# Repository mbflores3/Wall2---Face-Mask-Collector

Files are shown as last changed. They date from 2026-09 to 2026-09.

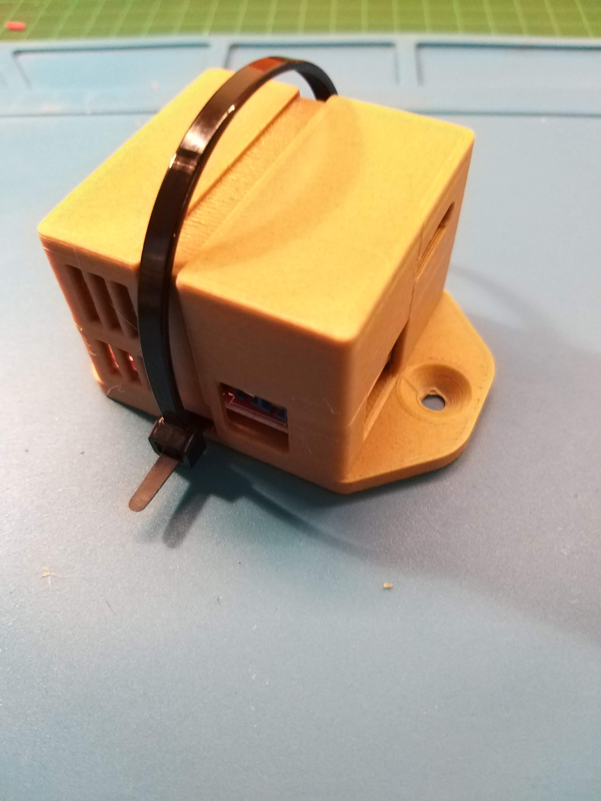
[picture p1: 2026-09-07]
Casing/3328541_L298N_Case_with_Zip-Tie_closure_and_Screw_holes_for_placement/images/20190102_104234.jpg

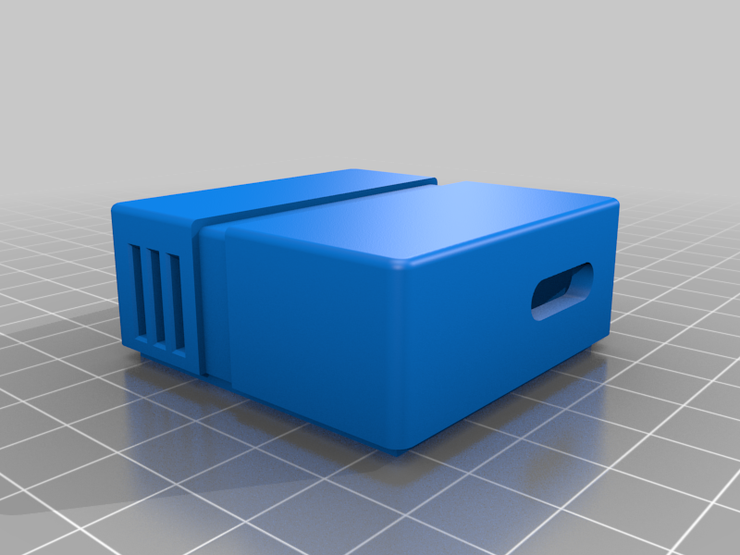
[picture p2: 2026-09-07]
Casing/3328541_L298N_Case_with_Zip-Tie_closure_and_Screw_holes_for_placement/images/L298N_Case_1.0.3c.png

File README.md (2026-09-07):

# Wall2---Face-Mask-Collector
## 1. User Manual

### 1.1. Required Hardware and Software

To begin this user manual, the components needed to build the prototype are listed below:

#### Mechanical Components:

• 2 MDF boards, 6mm thick, 600 x 440 mm (one for each floor).

• 2 rigid couplings, 5mm to 8mm.

• 2 rigid couplings, 8mm to 8mm.

• 4 rigid couplings, 6mm to 8mm.

• 4 Monster Truck toy wheels for sand.

• 4 dowels with nuts.

• 4 axles, 8mm in diameter and 8cm long.

• 2 kg of PLA 3D printing material.

• 1 trash can, 190mm wide.

• Screws and nuts of various diameters.

• 4 L-type couplings for Pololu DC motors.

• 4 Bearing Mounts

#### Electrical Components:

• ESP32 dev kit

• Arduino MEGA

• Raspberry Pi 4b

• 6 PC817 Optocouplers

• 6 Pre-drilled Breadboards (11cm x 6cm, 6cm x 4cm, 7cm x 3cm x4)
• 12 10kΩ Resistors

• Male Pin Header

• Female Pin Header

• 2 XH-M400 8A Step-Down Voltage Regulators

• 2 L298N H-Bridges

• 4 Pololu 12V DC Motors with Encoders

• 4 MG995 Servo Motors

• 1 ADXL345 Accelerometer-Gyroscope
• 2 11.1V 2200mAh LiPo Batteries

• 1 x 14.8V 5200mAh LiPo battery

• 3 x 2-pin 21x15mm switches

• 2 x XT60 female connectors

• 1 x XT60U-F female connector

• 1 x 640x480 pixel webcam

• 1 x HC-SR04 sonar sensor

• Logic jumper wires and power cables

• 2 x Arduino-type USB cables

• 1 x USB Type-C cable

• Cable ties

#### Software, knowledge, and computing tools requirements

• Arduino IDE

• 1 computer with a Python programming environment (preferably VS Code)

• Operating system installation software (preferably Rufus)

• Raspberry Pi operating system

• Minimum Python libraries: NumPy, Serial, OpenCV, Imutils, Time, SciPy
• Minimum Arduino Libraries: Simple_MPU6050, Servo.

#### Other necessary tools

• 3D printer.

• CNC laser cutter.

• Allen wrench set.

• Screwdriver set.

• Pliers.

• Hot glue gun.

### 1.2. Installation, assembly, and configuration

#### Assembly:

• Cut the MDF wood panels with the laser cutter. The first panel is cut according to the design in the Piso1_v1.dxf file, and the second according to the Piso2_v2.dxf file. These pieces correspond to floors one and two of the prototype.

• 3D print the component housings using the following files: motor_housing.ipt for the motors, L298N_Case_1.0.3b.stl and L298N_Case_1.0.3c.stl for the H-bridges, arduino_mega_case.ipt for the Arduino Mega, and battery_housing.ipt and lipo_housing.ipt for the batteries.

• On the board corresponding to the first level, assemble the DC motors with their respective L-shaped brackets. Then, place a 6-8mm coupling between the motor shaft and an 8mm shaft, one bearing per motor, and place them inside their respective housings and screw them in.

• Place the H-bridges inside their respective housings and screw them between the motors (one for every two motors).

• Using a hot glue gun, glue three optocouplers next to each H-bridge. The optocouplers should be arranged in parallel from the H-bridges towards the center of the chassis. • Using the pre-drilled boards, design the PCBs described in Appendix 7.3 and carefully attach them to the chassis as needed.

• Place the Arduino Mega in its housing and assemble it to the chassis in the most suitable location (preferably near the optocouplers).

• Connect the couplings to the wheels and assemble them to the shaft of each motor.

• Place the batteries in their housings and assemble them on the back of the motor.

• Assemble the arm with the respective servos and position them inside according to the arm's schematics presented in the low-level diagram.

• Place the servos on the arm's base in their respective housings and then attach the base to the arm.

• Assemble the arm to the chassis.

#### Connections:

• Connect an on/off switch to each battery.

• Connect four wires (two power and two ground) to the output of a battery. Connect these wires to the two H-bridges (one power and one ground for each H-bridge).
• Connect six wires from the H-bridges, corresponding to logic pins, to the optocouplers.
• Connect six wires from the optocouplers to a PCB (available in Appendix 7.3). This PCB receives the signals from the optocouplers and connects to the Arduino Mega at the corresponding pins (available in the low-level diagram).
• Connect the motor encoders to the PCB in a way that allows easy connection to the ESP32.
• The ESP32 receives the encoders, a power wire, and a ground wire.
• Once the connections are made and the second level is assembled, connect the Raspberry Pi to the Arduino Mega via serial communication. This will allow you to send information to the Arduino to control the motors.

• Connect the webcam to the Raspberry Pi via serial communication.

#### Software Installation:

• Go to the official Raspberry Pi website to download the operating system.

• Download the OS called "Raspberry Pi OS (64-bit)".

• Download Rufus from its official website.

• Open Rufus, select the downloaded operating system, and connect the SD card where you will create the partition. Start the installation process.

• Once the process is complete, remove the SD card and insert it into the Raspberry Pi.

• Connect the Raspberry Pi to a monitor via HDMI, and connect a mouse and keyboard. Then, power on the Raspberry Pi.

• Follow the installation instructions.

• Open Rufus, select the downloaded operating system, and connect the mouse and keyboard. • After installing the OS, open a terminal and run the following commands:

$ pip 3 install numpy
$ pip 3 install script
$ pip 3 install multils
$ pip 3 install opencv-python

• Transfer the .py files from the code folder.

• Upload the Wall2_MARK5.ino file to the Arduino Mega and the Wall2_ESP32.ino file to the ESP32 using the Arduino IDE.

• Connect the Arduino Mega and the ESP32 to the Raspberry Pi using a USB connection.

### 1.3. Instructions for use
• Turn on the power switch for the Raspberry Pi and the other controllers.

• Turn on the power switches for the motors and servos.

• Run the code “Wall2_MARK5.py”

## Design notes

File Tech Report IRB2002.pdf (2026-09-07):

IRB2002 – Diseño de Sistemas Robóticos

Escuela de Ingeniería / Major en Sistemas Autónomos y Robóticos

Pontificia Universidad Católica de Chile

# Informe Final

## Diseño de Sistemas Robóticos

## Grupo N◦ 3

## Mario Flores Martín Gallegos Agustín Mondinelli Jorge Pérez

12.12.2022

IRB2002 – Diseño de Sistemas Robóticos

Pontificia Universidad Católica de Chile

## Tabla de Contenidos

3.1. | Comparación de primera carta Gantt con el desarrollo del proyecto . . . . | 24
© Escuela de Ingeniería / Major en Sistemas Autónomos y Robóticos. | 2

Pontificia Universidad Católica de Chile | Informe Final

## 1. Estado final del proyecto

### 1.1. Descripción del proyecto

En los últimos años, dada la contingencia sanitaria, se ha evidenciado el incremento de residuos quirúrgicos desechados en lugares públicos como calles, parques y playas, y en particular, la contingencia ha llevado al aumento en casi un 9000% los residuos de mascarillas solo entre marzo y octubre del 2020 [1], lo que implica en un riesgo para la salud de las personas que concurren a estos lugares. Por lo tanto, la solución que se propone es un robot capaz de recorrer las playas para recoger y almacenar mascarillas que se encuentran tiradas por donde éste circule. El robot tendrá la capacidad de reconocer lo que es una mascarilla para poder recogerla. Además, otra característica que tendrá es que su movimiento no requerirá de la presencia humana para funcionar y operar. Y, por último, el robot tendrá un sistema de almacenamiento que le permita llevar todas las mascarillas que encuentra, y así poder trasladarse de manera más óptima.

### 1.2. Requerimientos

Los requerimientos que nos hemos propuesto para que el proyecto cumpla con los objetivos son los siguientes.

- Tiempo de recolección máximo dos veces inferior a un humano promedio.
- Tiempo de autonomía de por lo menos una hora.
- Área de trabajo: 128 m²
(área de cancha de voleibol).
- Capacidad de resistencia y adaptación a terrenos adversos (viento, arena y humedad).
- Sistema de detección y recolección de mascarillas.
- Capacidad de reconocer el entorno para recorrer un área delimitada.

Respecto al primer requerimiento, no se logró cumplirlo. Esto se debe principalmente a la manera en que se desarrollaron los movimientos del robot desde que detecta una mascarilla hasta que la recoge, siendo esto un proceso lento. Si se hubiera implementado un control PID más fino y que el movimiento del brazo robótico actuara al mismo tiempo en que el robot se desplaza, entonces se hubiera recolectado mascarillas en un menor tiempo que el obtenido.

Ahora bien, sobre el segundo objetivo, no se ha logrado comprobar que el robot tenga una autonomía de al menos una hora, ya que no se han hecho pruebas durante tanto tiempo sin detenerse. Pero considerando que una batería estaba solamente destinada a alimentar los motores DC y otra batería destinada a alimentar los Servo Motores, entonces estimamos que el robot sí puede cumplir con este requerimiento.

© Escuela de Ingeniería / Major en Sistemas Autónomos y Robóticos. | 3

Sobre el área de trabajo que se estableció en 128 m²
, consideramos que el robot es capaz de cumplir con el tercer requerimiento. Ahora bien, se mencionó anteriormente que nunca se han hecho pruebas para verificar si el robot efectivamente tiene una autonomía de al menos una hora, por lo que tampoco se sabe si es capaz de recorrer toda el área sin problemas. Pero sabiendo la capacidad de las baterías, entonces permite pensar que sí cumple con el objetivo.

Respecto al cuarto requerimiento, se ha comprobado que un poco de viento no afecta al funcionamiento ni a los componentes del robot. Por otro lado, el robot nunca fue expuesto a humedad, por lo que no podemos concluir nada respecto a esto. Pero sobre la arena, hemos construido un robot que no es completamente sellado, y por lo tanto durante las pruebas efectuadas, al robot le entró mucha arena donde se encuentran los componentes, aunque ninguno de ellos falló durante las pruebas. Para lograr este requerimiento se debe sellar al robot por completo y que ninguno de los componentes quede expuesto a estar en contacto con la arena.

Por otro lado, sobre el quinto requerimiento, se ha cumplido de buena manera con la implementación del sistema de detección y recolección de mascarillas. Gracias al código desarrollado para segmentar y detectar una mascarilla, y también al código que permite ejecutar los movimientos del brazo robótico, como resultado se obtuvo una segmentación bastante precisa y una fluidez en el movimiento del brazo.

Finalmente, sobre el sexto requerimiento, finalmente se descartó la idea de que el robot sea capaz de reconocer el entorno y sus límites. Lo que se hizo fue implementar un protocolo que recorre un camino definido según la distancia que se traslada. Pero el problema con esto es que finalmente se quemó la ESP32, la cual estaba encargada de leer los encoders de los motores DC, por lo que en el protocolo se cambió distancia recorrida por tiempo de ejecución, lo que no es muy factible en la práctica.

### 1.3. Especificaciones

Las especificaciones requeridas se pueden clasificar según el área de aplicación.

- Mecánicas

– Ruedas con diseño para tracción en arena.

– Material de chasis resistente a la arena y humedad.

– Sistema de pick-up con dos grados de libertad

– Recipiente disponible para almacenamiento de mascarillas con orificios para filtrado de arena.

– Mecanismo accionador capaz de sostener objetos de por lo menos 50g (Peso mascarillas + arena residual).

- Eléctricas
© Escuela de Ingeniería / Major en Sistemas Autónomos y Robóticos. | 4

– Regulador de voltaje para componentes electrónicos (Sensores y Actuadores).

– Motores DC con capacidad de torque suficiente para el objetivo propuesto (Dependiendo si son para tracción o para sistema de pick-up, desde 0.504 hasta 2.24 Nm).

– Sensor de distancia para retroalimentar el sistema de pick-up (Sonar).

– Fuente de alimentación: 2 baterías de 11.1 V y 2200 mah, considerando 4 motores de tracción de 150 ma, 2 servomotores de 300 ma, y la alimentación de microcontroladores que es de 1300 ma en sus puntos críticos.

– Sensores de orientación y aceleración para retroalimentar el estado del robot (Giroscopio y acelerómetro).

- Computacionales

– Algoritmo de segmentación de mascarillas mediante procesamiento de imágenes.

– Protocolo de exploración del área de trabajo.

– Proceso de filtrado para estimación del estado del robot.

– Microcontrolador con capacidad de procesamiento y memoria suficiente para cumplir con los algoritmos escogidos.

– Capturadora de imágenes de resolución de al menos 416 x 416 y un frame rate de por lo menos 2fps.

### 1.4. Normas y Estándares

A continuación se mencionan los estándares que fueron elegidos para construir el robot.

- ISO 18646-1:2016 [2]: Define métodos y criterios para evaluar el rendimiento de un robot de servicio. Este estándar se enfoca específicamente en el desplazamiento de robots con ruedas. Resulta útil para evaluar el movimiento del robot en desarrollo.
- ISO 18646-3:2021 [3]: Define métodos de evaluación de rendimiento de robots de servicio en la manipulación de objetos. Se evalúan aspectos como: tamaño del manipulador, fuerza de agarre, resistencia al deslizamiento, entre otros. Resulta útil para desarrollar un sistema de pick-up adecuado.
- Certificación IP [4]: Según la numeración de la certificación, se establece el grado de resistencia que tiene un sistema eléctrico a la exposición de polvo y agua. En el caso de este proyecto, la certificación necesaria corresponde a IP66.
- ISO 19649:2017 [5]: Entrega definiciones y vocabulario frecuentemente utilizados en robótica.

Nuestro robot en uno tal que utiliza 4 ruedas para desplazarse. Por lo que, sobre el estándar ISO 18646-1:2016, nuestro robot cumple con las especificaciones, puesto que es capaz de moverse de buena manera y rápida sin presentar problemas.

© Escuela de Ingeniería / Major en Sistemas Autónomos y Robóticos. | 5

Por otro lado, consideraos que el robot cumple con el estándar ISO 18646-3:2021, ya que hemos sido capaces de implementar un brazo tal que tiene un tamaño bastante reducido y liviano, la fuerza que realiza es suficiente y la mascarilla no se resbala o cae cuando el gripper logra agarrarla. Considerando todo esto, entonces el sistema de pick-up implementado es adecuado para lo que se necesita.

Ahora bien, sobre la certificación IP66, no se puede concluir nada sobre si el sistema eléctrico resiste a la exposición de agua, ya que no se realizaron pruebas con agua o en un ambiente húmedo. Pero sobre la resistencia al polvo, o en este caso a la arena, si bien el sistema eléctrico estuvo muy expuesto a la arena, pero ninguno de los componentes falló debido a esta situación, por lo que no fue posible verificar si el robot es capaz de cumplir con dicha certificación.

### 1.5. Diagrama de Alto Nivel

El diagrama de alto nivel final se encuentra en la figura 1, la cual se divide en 6 bloques principales: Fuente de alimentación, acondicionamiento, controlador, sensores, actuadores y aislamiento.

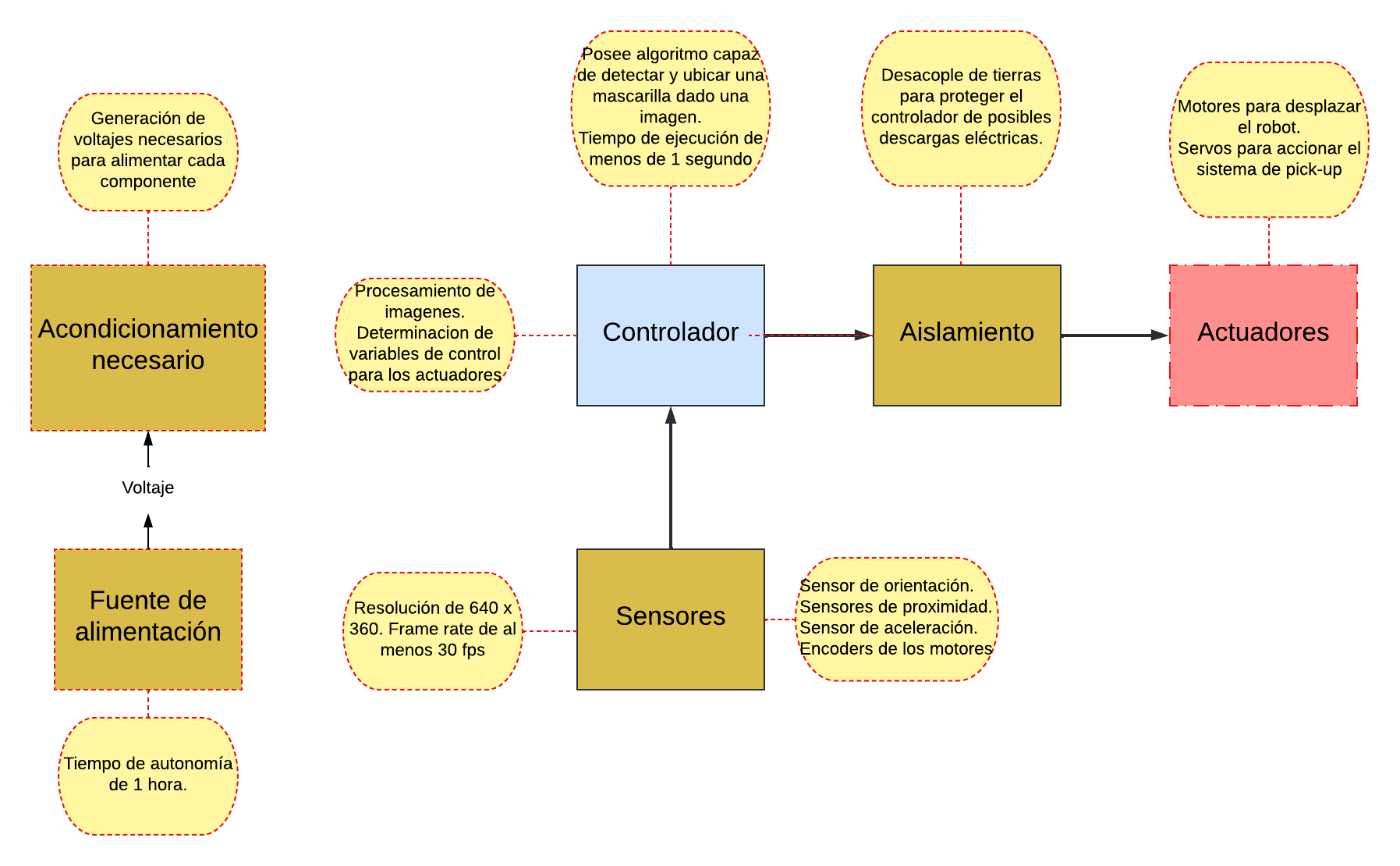
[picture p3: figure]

Figura 1: Diagrama de alto nivel

© Escuela de Ingeniería / Major en Sistemas Autónomos y Robóticos. | 6

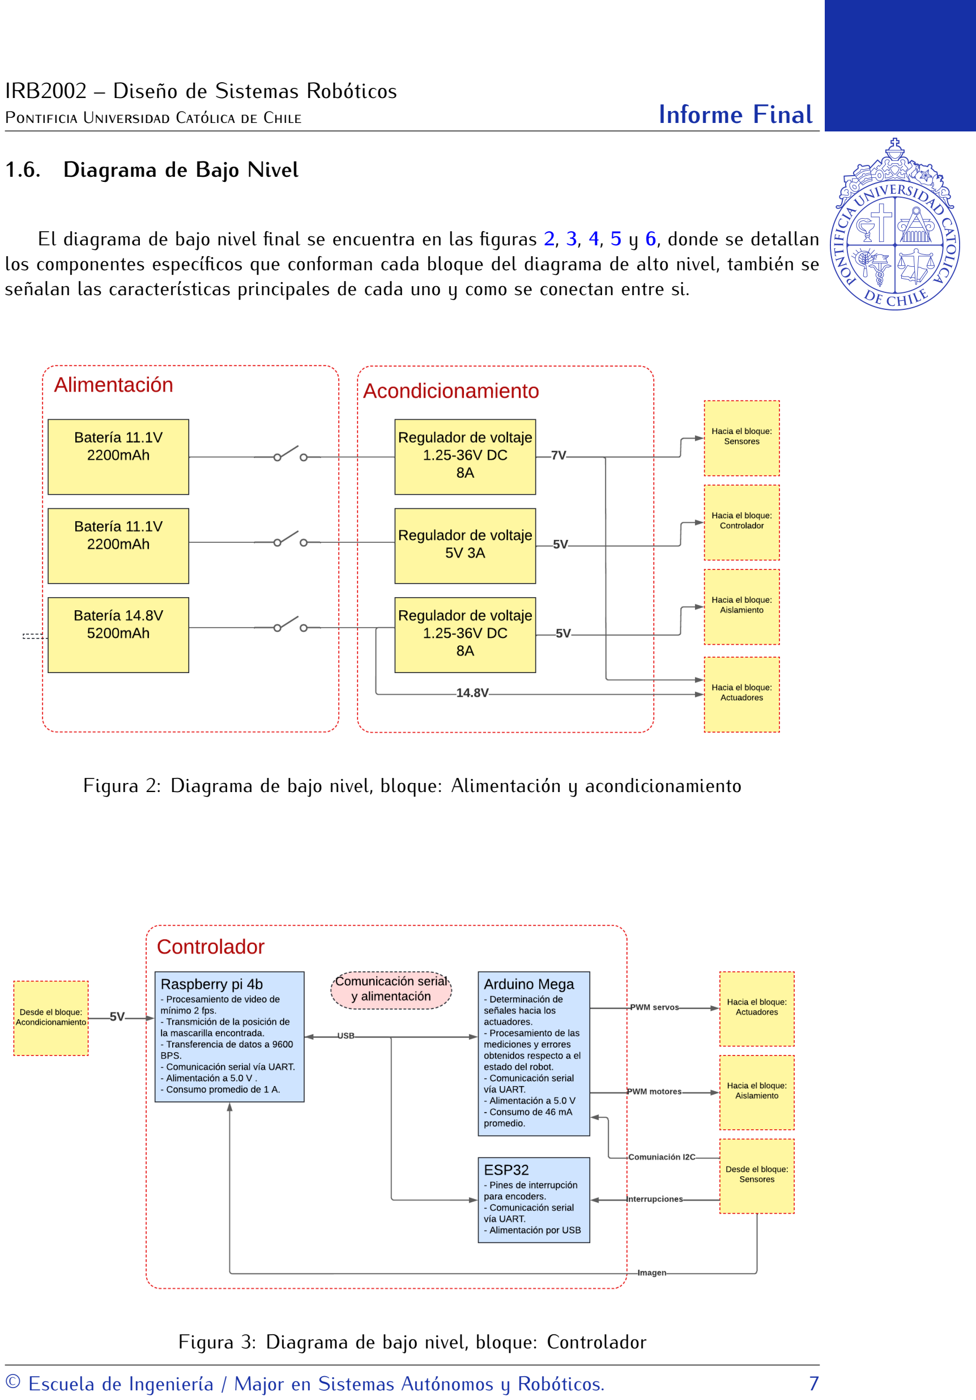
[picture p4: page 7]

### 1.6. Diagrama de Bajo Nivel

El diagrama de bajo nivel final se encuentra en las figuras 2, 3, 4, 5 y 6, donde se detallan los componentes específicos que conforman cada bloque del diagrama de alto nivel, también se señalan las características principales de cada uno y como se conectan entre si.

Figura 2: Diagrama de bajo nivel, bloque: Alimentación y acondicionamiento

Figura 3: Diagrama de bajo nivel, bloque: Controlador

© Escuela de Ingeniería / Major en Sistemas Autónomos y Robóticos. | 7

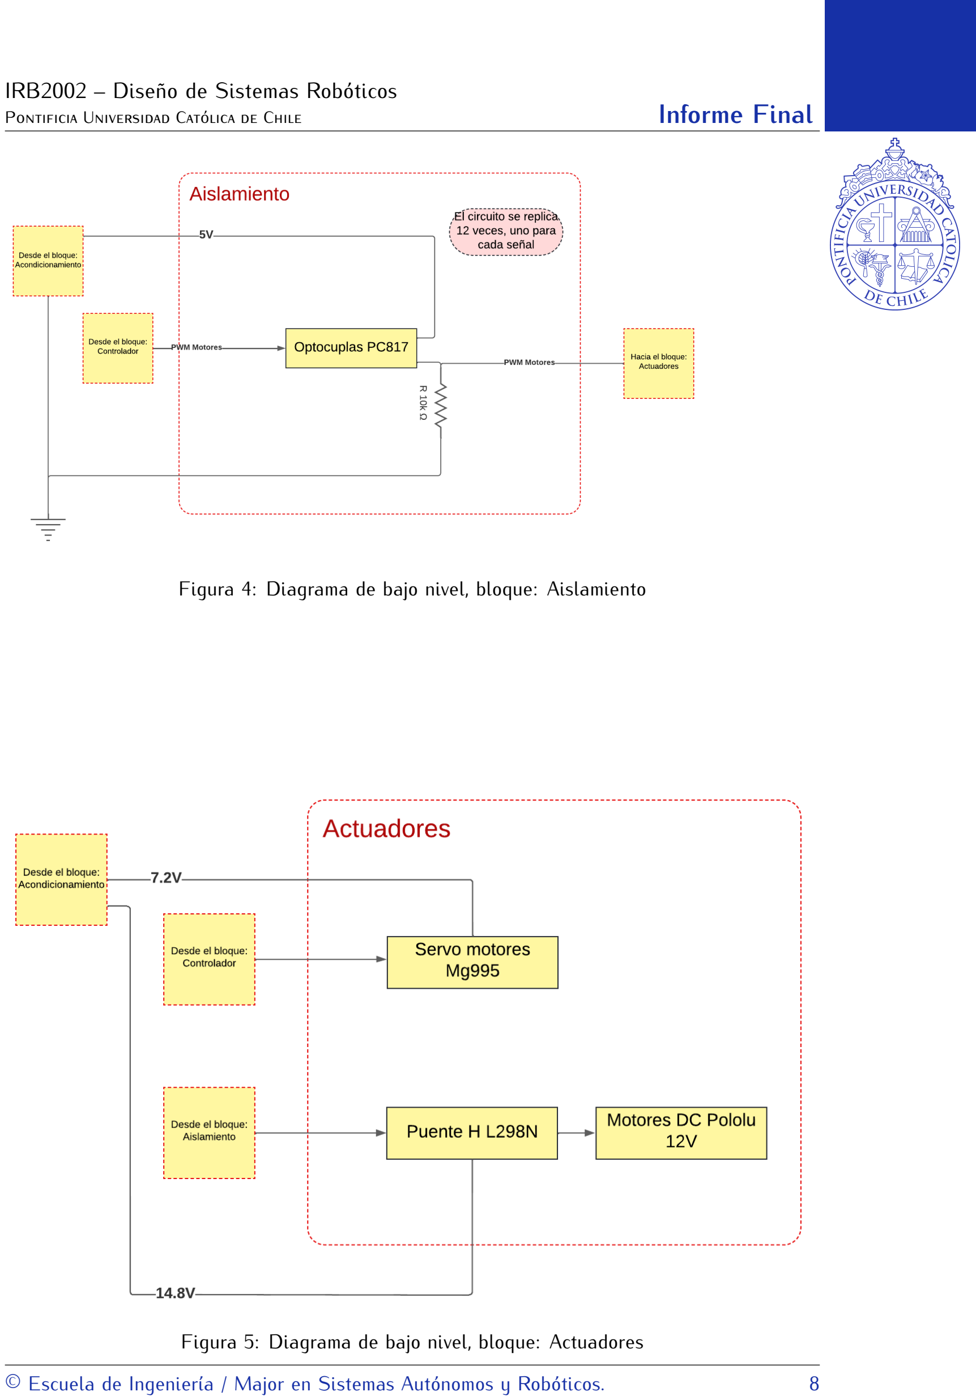
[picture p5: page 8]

Figura 4: Diagrama de bajo nivel, bloque: Aislamiento

Figura 5: Diagrama de bajo nivel, bloque: Actuadores

© Escuela de Ingeniería / Major en Sistemas Autónomos y Robóticos. | 8

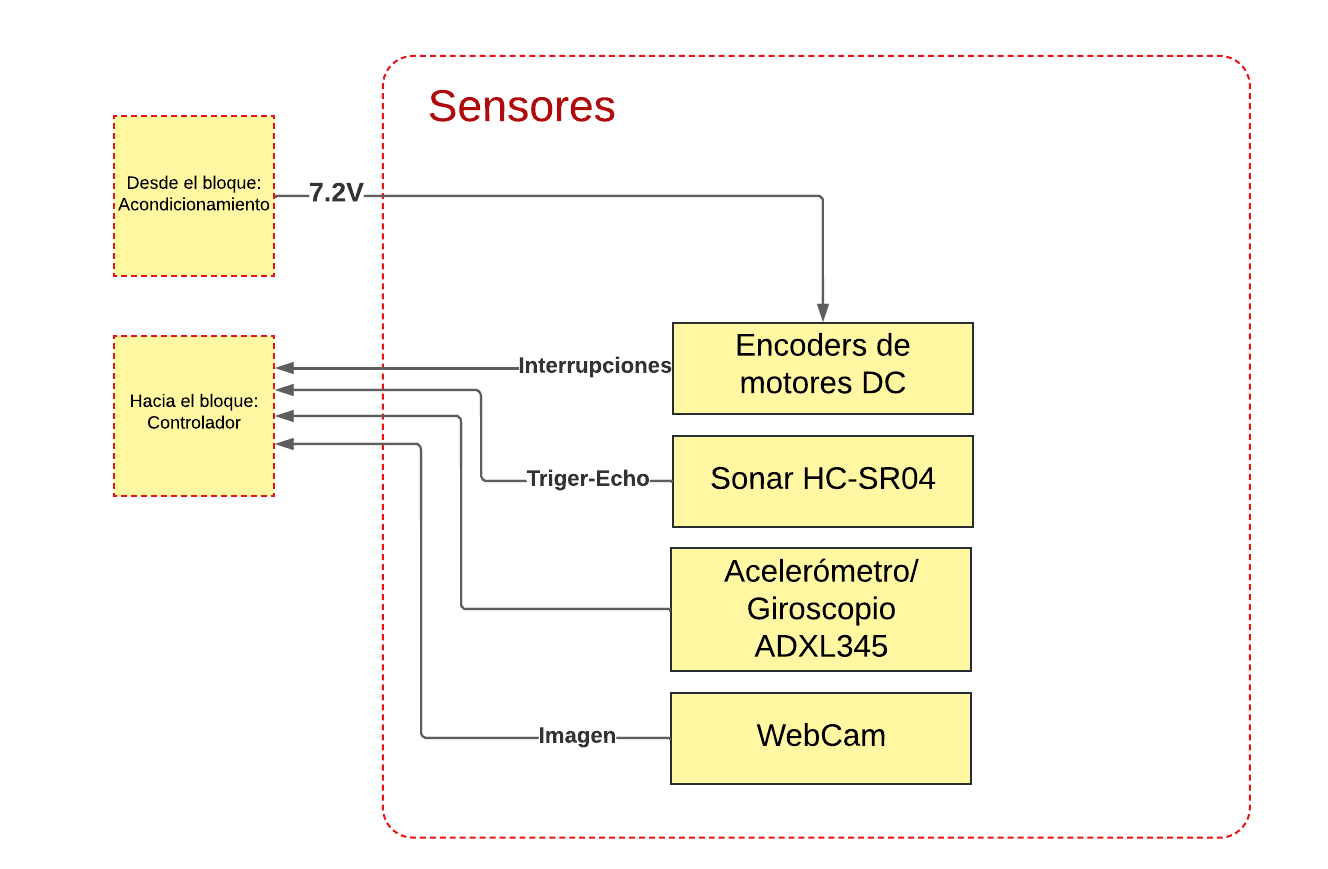
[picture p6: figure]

Figura 6: Diagrama de bajo nivel, bloque: Sensores

## 2. Descripción de diagrama de bajo nivel

### 2.1. Alimentación

Descripción: El bloque de alimentación tiene como principal función entregar la energía necesaria para hacer funcionar el resto de componentes eléctricos que conforman al sistema. Este bloque se compone de 3 baterías Lipo: 2 de 11.V 2200mAh y uno de 14.8V 5200mAh, este último conecta directamente con los puentes H que alimentan a los motores DC para mover las ruedas. Por otro lado, una de las baterías se dedica exclusivamente para entregar energía a los componentes presentes en el bloque "Controladores", mientras que la batería restante se dedica a entregar energía a servomotores y algunos componentes del bloque "Sensores". Cada batería cuenta con un interruptor para encender o apagar diferentes bloques del sistema.

### 2.2. Acondicionamiento

Descripción: Este bloque tiene como función de entregar diferentes voltajes a la salida en base al voltaje de entrada proveniente del bloque "Alimentación", ya que los componentes presentes en los otros bloque requieren diferentes voltajes de entrada para funcionar adecuadamente. Este bloque cuenta con 3 reguladores de voltaje, donde dos de ellos corresponden a reguladores de voltaje variable XH-M400, los cuales fueron ajustados para entregar 7.2V y 5V a la salida

© Escuela de Ingeniería / Major en Sistemas Autónomos y Robóticos. | 9

respectiva de cada uno, mientras que el tercer regulador corresponde a un regulador de voltaje de 5V 3A.

### 2.3. Controlador

Descripción: Este bloque corresponde al área encargada de todo el procesamiento de alto nivel y la toma de decisiones del robot, este se compone de 3 elementos: una Raspberry Pi 4b [6], un Arduino Mega [7] y una ESP32[8]. La ESP32 se encarga de leer los datos entregados por los encoders de cada motor DC, de esta forma es posible calcular la velocidad a la que se desplaza el robot. Por otro lado, el Arduino Mega se encarga de leer los datos provenientes del sonar y del acelerómetro/giroscopio, mientras que envía señales de control a los motores del bloque "Actuadores". Finalmente, la Raspberry Pi tiene como función leer las imágenes registradas por la cámara web y enviar instrucciones al Arduino Mega en base a la información que entrega la imagen.

Diagramas de flujo: A continuación, se describe la lógica detrás del funcionamiento de cada elemento presente en este bloque:

- ESP32: El funcionamiento de este componente es simple, en cada ciclo del código, la ESP32 lee la información entregada por los encoders de los motores, estima la velocidad de cada rueda en revoluciones por minuto (RPM) y envía las velocidades calculadas a la Raspberry Pi mediante comunicación serial.
- Arduino Mega: El funcionamiento de este componente se resume de la siguiente forma: en primer lugar, el Arduino inicializa y calibra todos sensores conectados a él. Luego, el Arduino entra en un estado de espera, el cual permanece hasta registrar una instrucción entregada por la Raspberry Pi mediante comunicación serial. Luego de recibido correctamente el mensaje con la instrucción, el Arduino decodifica la información entregada y actúa en base a ella. Dentro de las instrucciones que recibe este componente se encuentran: un mensaje de STOP que le indica al Arduino detener todos sus motores, instrucciones para manejar la velocidad de los motores y un mensaje de PICK UP que indica que el Arduino debe ejecutar una secuencia de comandos a los servo motores para hacer que el brazo robótico se mueva y realice el gesto de recoger una mascarilla.
- Raspberry Pi: El funcionamiento de este elemento se divide en 2 estados principales: Exploración y Recolección, donde este último se subdivide en: Orientación, Acercamiento y Pick-UP. En el estado de exploración, la Raspberry Pi recibe la información proveniente del acelerómetro/giroscopio conectado al Arduino Mega, y en base a ello implementa un algoritmo de seguimiento de trayectorias, donde se utiliza un controlador PID que utiliza como función de error el error entre el ángulo actual medido y un ángulo de referencia, de modo que el robot se mantenga en una dirección en línea recta. De esta forma, es posible programar que el robot siga una trayectoria en particular solamente modificando el ángulo de referencia dependiendo de la curva que se desee formar. Mientras el robot sigue la trayectoria establecida, se leen constantemente las imágenes capturadas por la cámara, para posteriormente ser procesadas en un algoritmo de segmentación de mascarillas, el cual consiste en un algoritmo de segmentación HSV que ha sido calibrado para segmentar objetos de tonalidades azules-celestes, dado que un alto porcentaje de las mascarillas
© Escuela de Ingeniería / Major en Sistemas Autónomos y Robóticos. | 10

utilizadas actualmente presentan este color. En el caso en que la segmentación logra detectar un objeto, el robot cambia su estado de Exploración a Orientación. En este estado, el robot calcula el centro de masa del objeto detectado, para luego implementar un control PID basado en orientación, donde la función de error corresponde a la desviación del centro de masa con respecto al centro de la cámara, de esta forma, el robot rota hasta alinearse completamente con la mascarilla detectada. Cuando el error es lo suficientemente pequeño, el robot cambia su estado a Acercamiento, donde este utiliza un control PID basado en distancia para aproximarse a la mascarilla y localizarse a una distancia determinada, de modo que se encuentre a rango para poder ser recogida. Cuando el robot alcanza dicha distancia, se pasa inmediatamente al estado Pick-Up, donde la Raspberry Pi envía la instrucción de ejecutar la secuencia de movimientos del brazo robótico para recoger la mascarilla. Una vez finalizado el proceso, el programa vuelve al estado de Exploración. Para evitar colisiones con objetos en movimiento, se lee constantemente los valores entregados por el sonar ubicado en el brazo del robot, donde se enviará una señal de STOP en el caso de que se registre un objeto demasiado cerca.

Dado que el robot no funcionó correctamente en la presentación final, es necesario aclarar los puntos que no lograron ser implementados de forma adecuada, donde, en pocas palabras, se logró implementar los diferentes estados de forma independiente, pero no se pudieron integrar adecuadamente para formar el flujo principal. Tampoco se pudo comprobar que la sección de de freno de emergencia se implementó correctamente.

Los diagramas de flujo se presentan a continuación:

© Escuela de Ingeniería / Major en Sistemas Autónomos y Robóticos. | 11

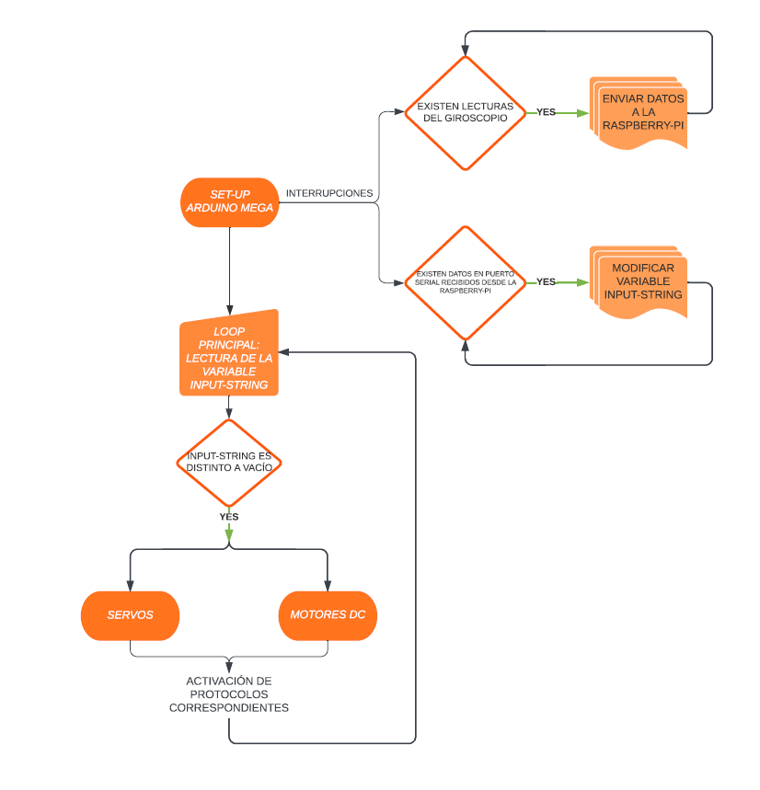
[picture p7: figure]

Figura 7: Diagrama de flujo del funcionamiento de Arduino Mega

© Escuela de Ingeniería / Major en Sistemas Autónomos y Robóticos. | 12

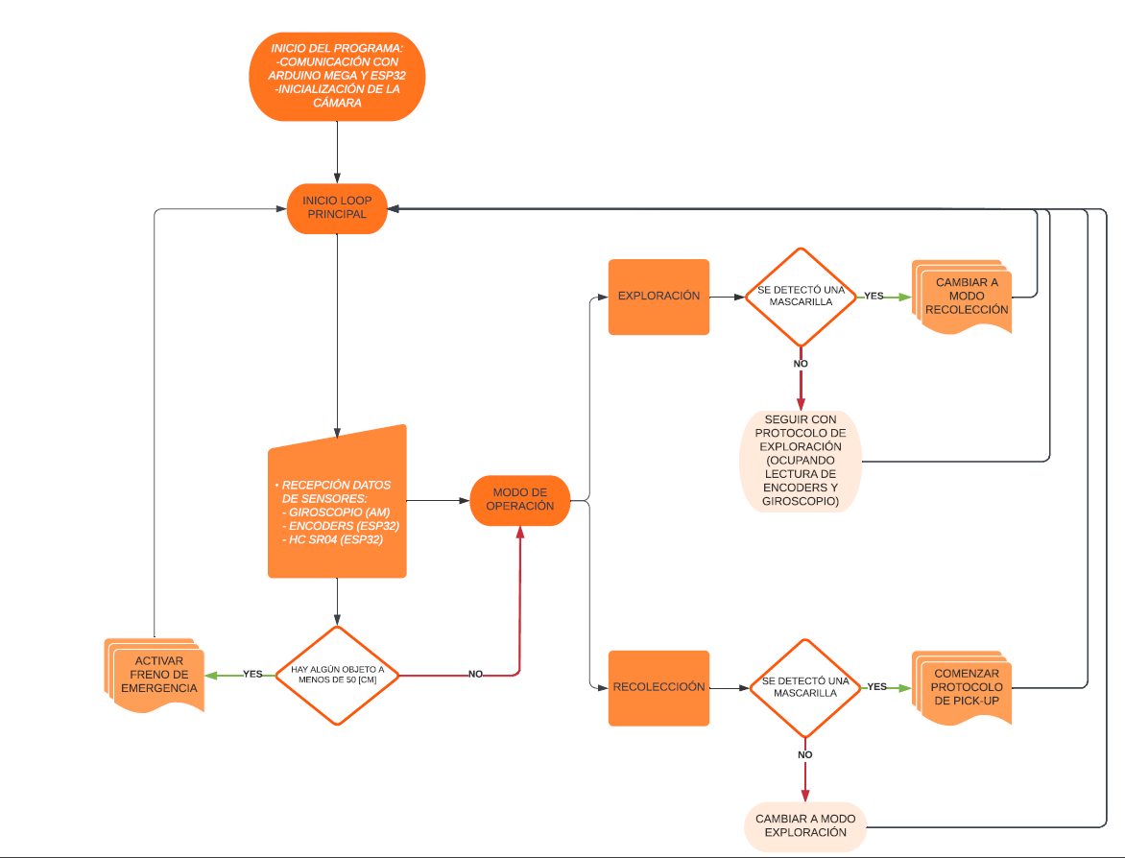
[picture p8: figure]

Figura 8: Diagrama de flujo del funcionamiento de Raspberry Pi

### 2.4. Aislamiento

Descripción: Este corresponde a un bloque nuevo considerando la versión anterior del diagrama. Este tiene como función desacoplar las señales generadas por el Arduino y entregarlas a los puentes H que controlan los motores, esto se hace con el fin de proteger los componentes vitales del sistema ante cualquier falla o peak de corriente generado en los puentes H. El bloque consiste en 12 optocuplas PC817[9], los cuales consisten en un led infrarrojo conectado a cada señal proveniente del Arduino, dicha señal excita al led, lo que hace encenderse o apagarse según corresponda, la luz generada es captada por un foto-transistor que circula corriente según la luz que recibe, el pin negativo es conectado a una resistencia de pull-down y luego a la tierra respectiva del puente H, este pin también conecta con las conexiones respectivas de los puentes H y el pin positivo se conecta a una alimentación de 5V. De esta forma, las señales son transmitidas al puente H sin tener una conexión directa con el Arduino.

© Escuela de Ingeniería / Major en Sistemas Autónomos y Robóticos. | 13

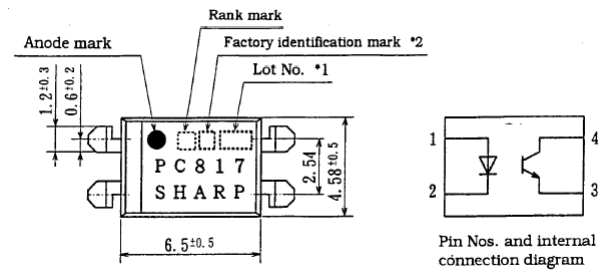
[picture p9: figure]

Figura 9: Optocupla PC817 [9]

### 2.5. Actuadores

Descripción: Este bloque contiene todos los elementos necesarios para que el robot se desplace e interactúe con su entorno. En particular, este bloque se compone de 4 motores DC Pololu 37D de 12V[10] y 4 servo motores Mg995[11]. Para controlar las velocidades de cada motor, se utilizan 2 puentes H L298N[12].En el caso de los motores DC, estos se encuentran ensamblados a su respectivo soporte en forma de L, el que a su vez se encuentra ensamblado a una plancha de madera MDF de 6mm de espesor. Por otro lado, los servo motores se encuentran ensamblados a un brazo robótico formado por piezas fabricadas con impresoras 3D.

Cálculos : En el anexo 7.2 de este informe se encuentran los cálculos efectuados para determinar los torques y velocidades angulares necesarios para desarrollar el robot.

Planos mecánicos:

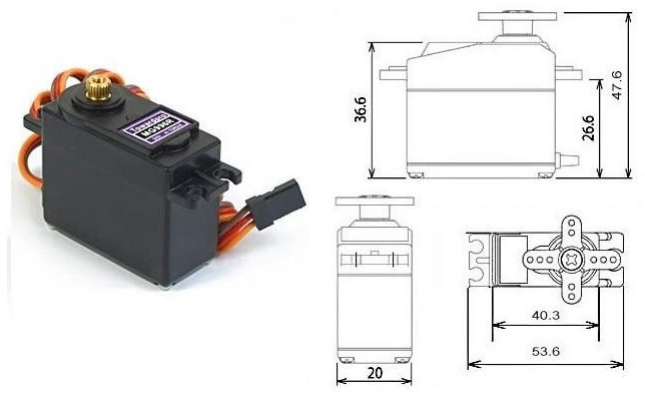
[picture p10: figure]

Figura 10: Servo motor Mg995 [11]

© Escuela de Ingeniería / Major en Sistemas Autónomos y Robóticos. | 14

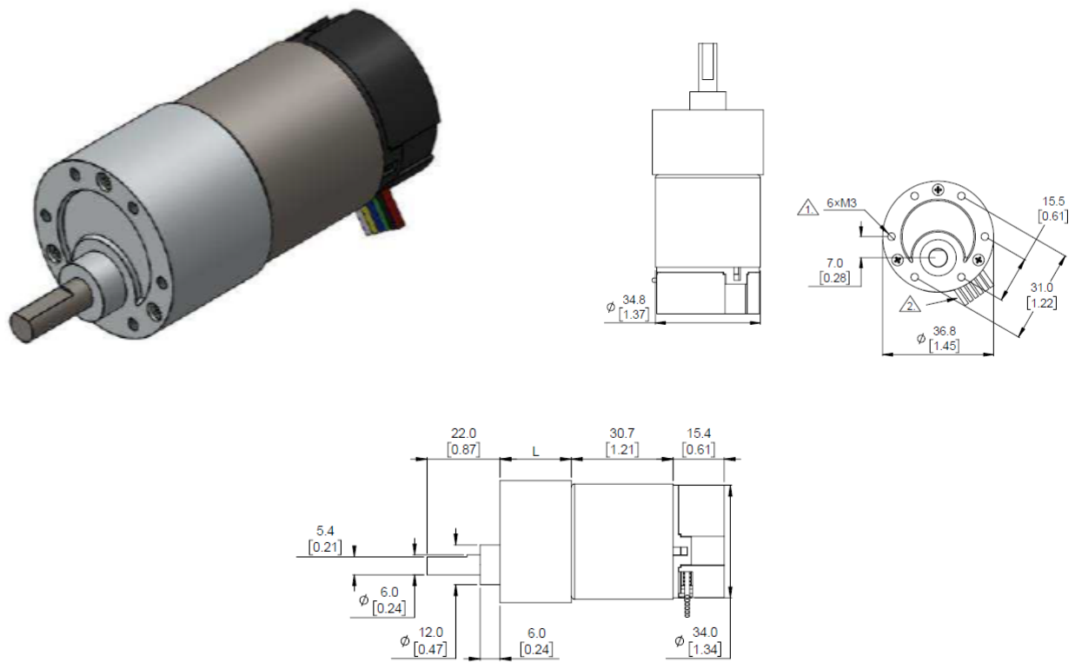
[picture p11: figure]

Figura 11: Motor DC pololu 37D [10]

© Escuela de Ingeniería / Major en Sistemas Autónomos y Robóticos. | 15

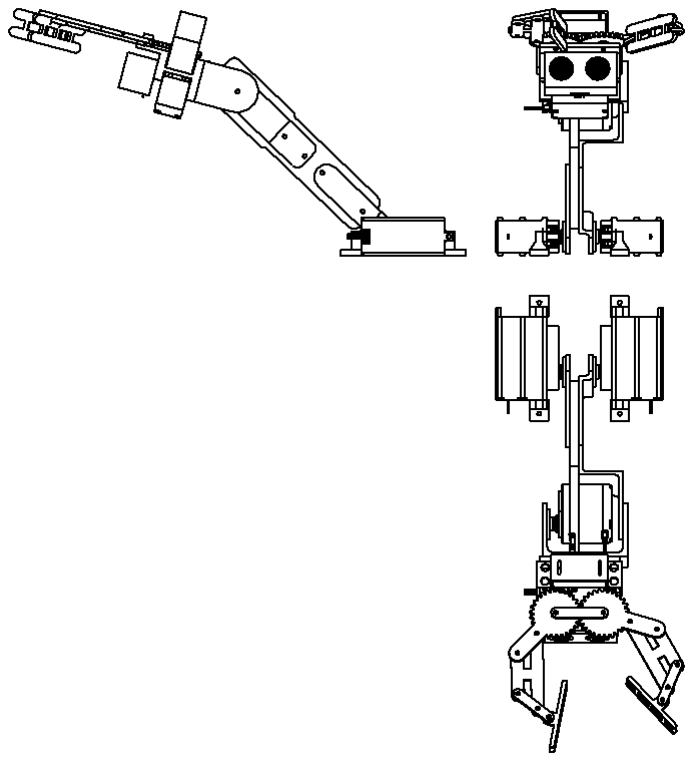
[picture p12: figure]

Figura 12: Vistas de ensamblaje de brazo robótico

© Escuela de Ingeniería / Major en Sistemas Autónomos y Robóticos. | 16

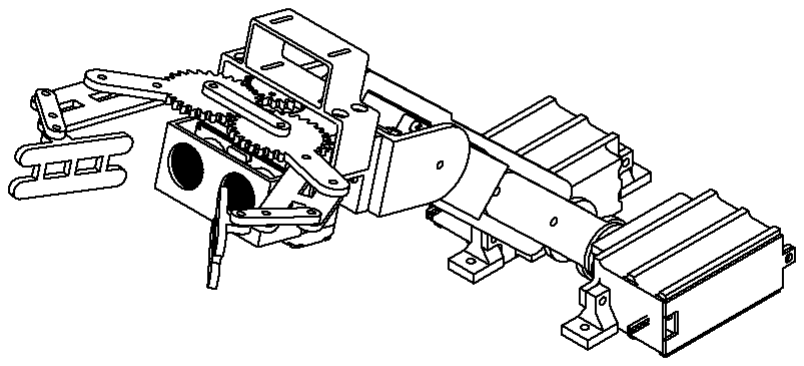
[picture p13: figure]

Figura 13: Vista isométrica de ensamblaje de brazo robótico

### 2.6. Sensores

Descripción: Este bloque reúne todos los dispositivos encargados de entregar información del entorno al controlador. Se compone de 4 encoders provenientes de los motores DC Pololu, los cuales registran la velocidad a la que gira cada eje según un tren de pulsos generados por un sensor Hall, una cámara web, la cual captura imágenes de 640x320 de resolución en tiempo real, un sonar HC-SR04, el cual registra la distancia de objetos en base a tiempos de emisión y recepción de ultra sonidos, y un acelerómetro/giroscopio MPU6050[13], el cual, a grandes rasgos, funciona con un sistema de masa resorte (Giroscopio) que entrega velocidades angulares y un sistema piezoeléctrico (Acelerómetro) que transforma las aceleraciones en señales de voltaje, el cuál a través de ambas mediciones es capaz de entregar ángulos respecto a un maro de referencia dado al iniciar el sensor.

### 2.7. Avances generales

Fuera del avance realizado en los bloques anteriormente mencionados, se realizaron avances que engloban diferentes bloques, los cuales se describen a continuación:

Interconexión de bloques

Descripción: Para realizar la conexión física de los diferentes bloques del diagrama de bajo nivel, se diseñaron y fabricaron tarjetas PCB, los cuales cuentan con los tipos de conexión necesarios para cada componente. Además, las conexiones fueron distribuidas espacialmente, de forma tal que las conexiones lógicas se encuentren lo más distanciadas posibles de las conexiones

© Escuela de Ingeniería / Major en Sistemas Autónomos y Robóticos. | 17

de transmisión de potencia, con el fin de minimizar la probabilidad de que algún componente sensible resulte dañado producto de una falla eléctrica.

Diseño de PCB: Los diseños se encuentran adjuntados en el anexo 7.3 de este informe

Protecciones de componentes críticos

Descripción: Dado que el ambiente de trabajo del robot propuesto corresponde a una playa, este se verá expuesto a humedad y partículas de arena que pueden ingresar y dañar componentes tanto eléctricos como mecánicos. Por esta razón, se diseñaron e imprimieron piezas que tienen como finalidad cubrir la mayoría de componentes ante el ingreso de arena.

Planos mecánicos: Las piezas que fueron diseñadas se adjuntaron junto al presente informe. En el caso de la Raspberry Pi, se optó por una carcasa de metal.

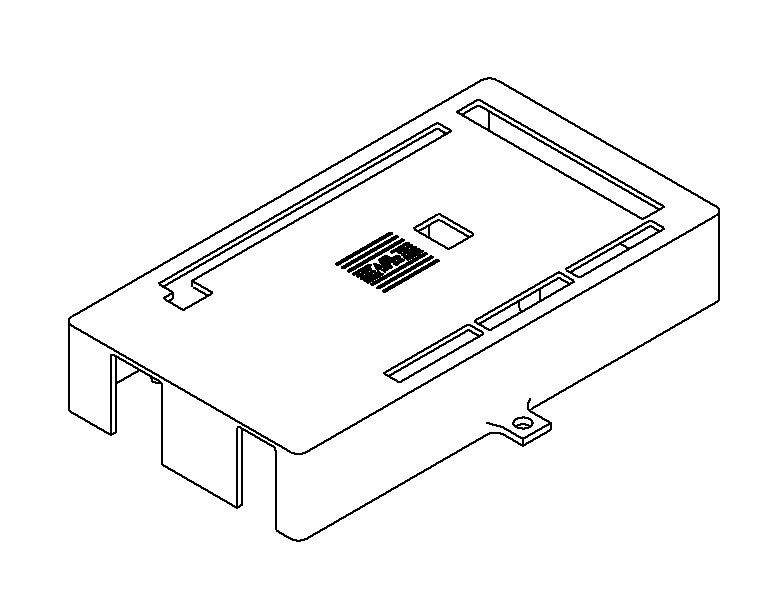
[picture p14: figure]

Figura 14: Protección Arduino Mega

© Escuela de Ingeniería / Major en Sistemas Autónomos y Robóticos. | 18

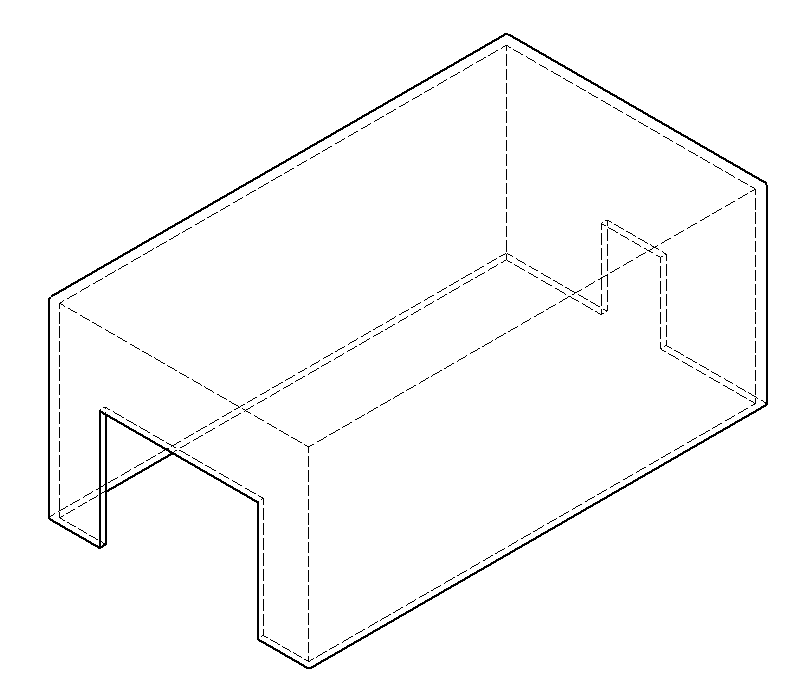
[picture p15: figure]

Figura 15: Protección ESP32

© Escuela de Ingeniería / Major en Sistemas Autónomos y Robóticos. | 19

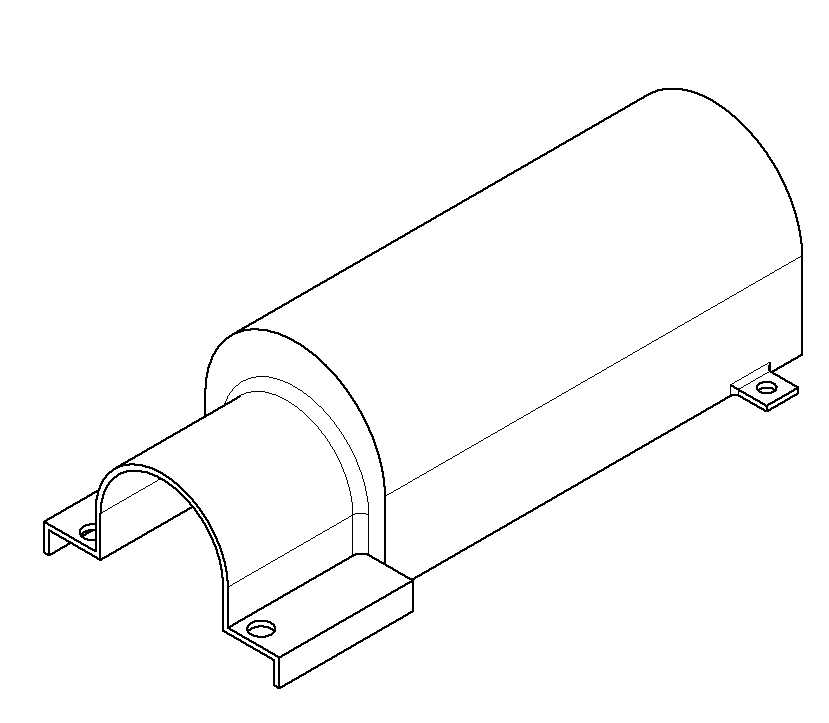
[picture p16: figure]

Figura 16: Protección de motores DC

© Escuela de Ingeniería / Major en Sistemas Autónomos y Robóticos. | 20

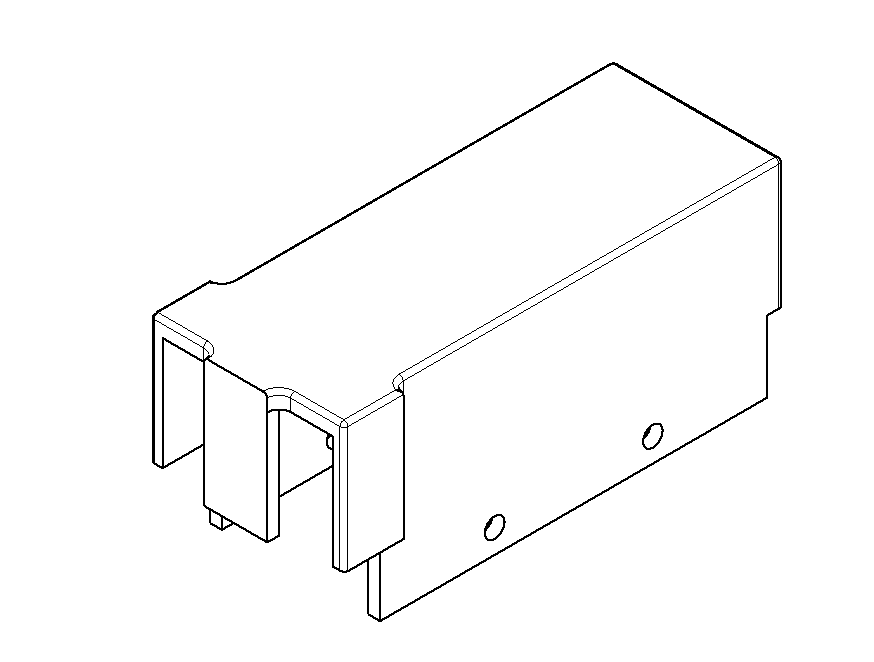
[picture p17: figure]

Figura 17: Protección de baterías Lipo 11.1V

© Escuela de Ingeniería / Major en Sistemas Autónomos y Robóticos. | 21

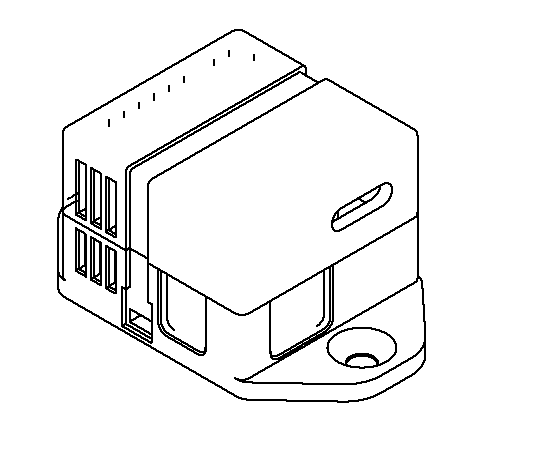
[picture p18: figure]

Figura 18: Protección de puente H. LINK (https://www.thingiverse.com/thing:3328541)

© Escuela de Ingeniería / Major en Sistemas Autónomos y Robóticos. | 22

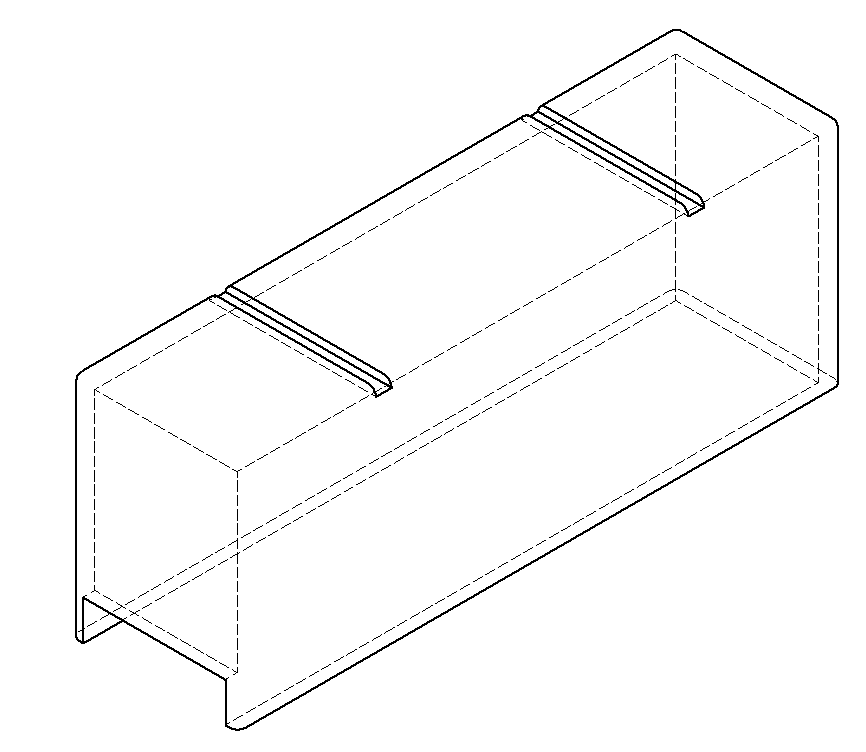
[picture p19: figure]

Figura 19: Protección de baterías Lipo 14.8V

Pruebas efectuadas: Para confirmar que las piezas diseñadas cumplen adecuadamente con su función, se realizó una prueba en terreno, donde se colocó el robot con sus respectivas protecciones, y se le dio la instrucción de desplazarse en la arena. Con esta prueba, se obtuvo como resultado que las protecciones lo gran evitar la filtración de arena al robot de forma adecuada. Sin embargo, dicha prueba con considera la posibilidad de que el robot se exponga a humedad, por lo que no se obtuvo información al respecto. Una observación importante es que, en el diseño final, existen componentes que no cuentan con su respectiva protección contra la arena, lo cual es un fallo grave en el diseño.

En conclusión, las protecciones diseñadas cumplen parcialmente uno de los objetivos propuestos, que corresponde al de que se debe ser resistente a la humedad y al polvo. Por otro lado, queda como aspectos a mejorar la incorporación de más protecciones para el resto del sistema.

© Escuela de Ingeniería / Major en Sistemas Autónomos y Robóticos. | 23

## 3. Planificación de Costos y Carta Gantt

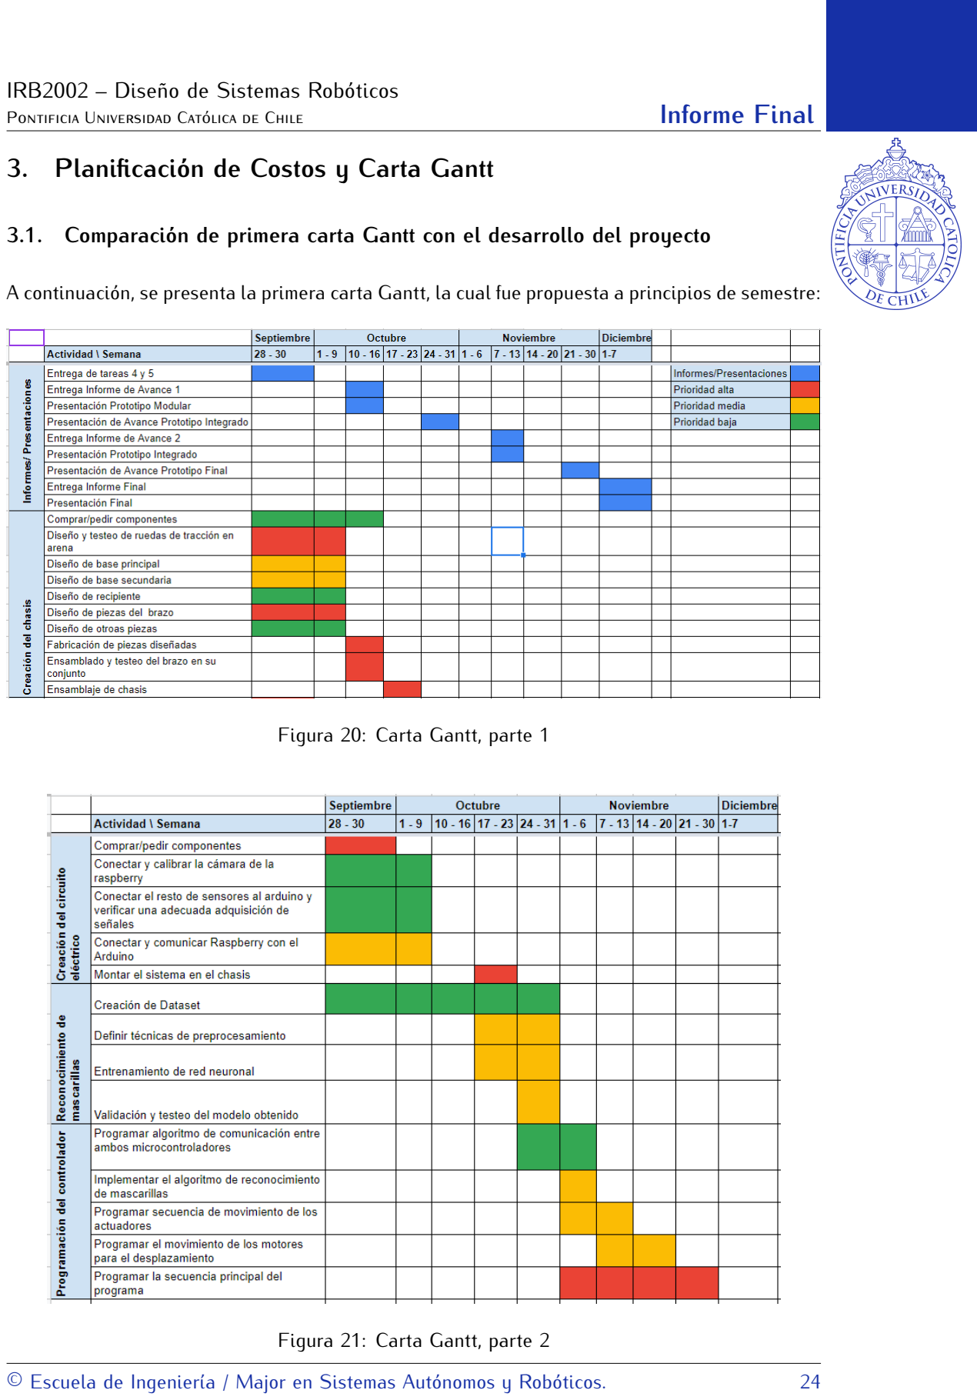
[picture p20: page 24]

### 3.1. Comparación de primera carta Gantt con el desarrollo del proyecto

A continuación, se presenta la primera carta Gantt, la cual fue propuesta a principios de semestre:

Figura 20: Carta Gantt, parte 1

Figura 21: Carta Gantt, parte 2

© Escuela de Ingeniería / Major en Sistemas Autónomos y Robóticos. | 24

Al comparar esta carta Gantt con el desarrollo real del proyecto, resalta la siguientes discordancias:

En primer lugar, una de las principales diferencias entre el desarrollo real y el propuesto, fue el diseño y testeo de las ruedas en arena, dado que solo se realizó una prueba dentro de los primeros meses, donde se utilizó una versión incompleta del robot para verificar si el diseño propuesto logra hacer tracción en arena. Luego, se realizó otra prueba en los últimos días con la versión final, en los que se pudo observar que el robot presenta ciertas dificultades en su movimiento, lo que dio como resultado que, en la presentación final, el robot no haya sido capaz de desplazarse de forma adecuada en arena.

Por otro lado, otra discordancia corresponde a que, en la versión inicial de la carta Gantt, no se consideró el diseño de tarjetas PCB dentro de los plazos disponibles, esto dio como resultados que el desarrollo se atrasara por lo menos por dos semanas, donde dichas semanas se dedicaron exclusivamente al diseño de las tarjetas PCB. La gran extensión de esta etapa de diseño se debe principalmente a la falta de conocimiento que se tenía como grupo en cuanto al diseño de PCB. Inicialmente, se consideró realizar un diseño de PCB propio, para luego ser fabricado la ruteadora que se encuentra en el departamento de ingeniería eléctrica de la universidad. Sin embargo, dicha ruteadora había sufrido un desperfecto, por lo que no estaba disponible. Como plan de contingencia, se utilizaron tarjetas pre-perforadas, las cuales tuvieron que ser construidas manualmente, es por esta razón que el atraso en el resto del proyecto fue tan severo.

Otra discordancia importante corresponde a la sección de creación del programa principal y el diseño del algoritmo de detección de mascarillas, este último sufrió grandes modificaciones a lo largo del tiempo. Originalmente, se había diseñado esta última sección pensando en que para la detección de mascarillas se utilizaría una red neuronal entrenada con un dataset creado con datos propios, pero esta idea tuvo que ser desechada principalmente por dos razones: primero, la capacidad de procesamiento de la Raspberry Pi disponible era bastante limitada, lo que provocaba que el programa se ejecute demasiado lento, segundo, se pudo notar que un algoritmo de segmentación basado en colores funcionaba con gran eficiencia. Por otro lado, el tiempo considerado para realizar el programa principal que integraba todos los bloques planteados en el diagrama de bajo nivel fue mucho menor al esperado, debido principalmente a los atrasos que se presentaron en los pasos anteriores, por lo que no se pudo desarrollar el programa principal completamente, y no se lograron corregir a tiempo los errores que surgieron mientras se programaba.

### 3.2. Planilla de costos totales

Las siguientes tablas detallan los costos de cada componente que compone el proyecto desarrollado, donde el costo total corresponde a $ 762.043,00 pesos chilenos:

© Escuela de Ingeniería / Major en Sistemas Autónomos y Robóticos. | 25

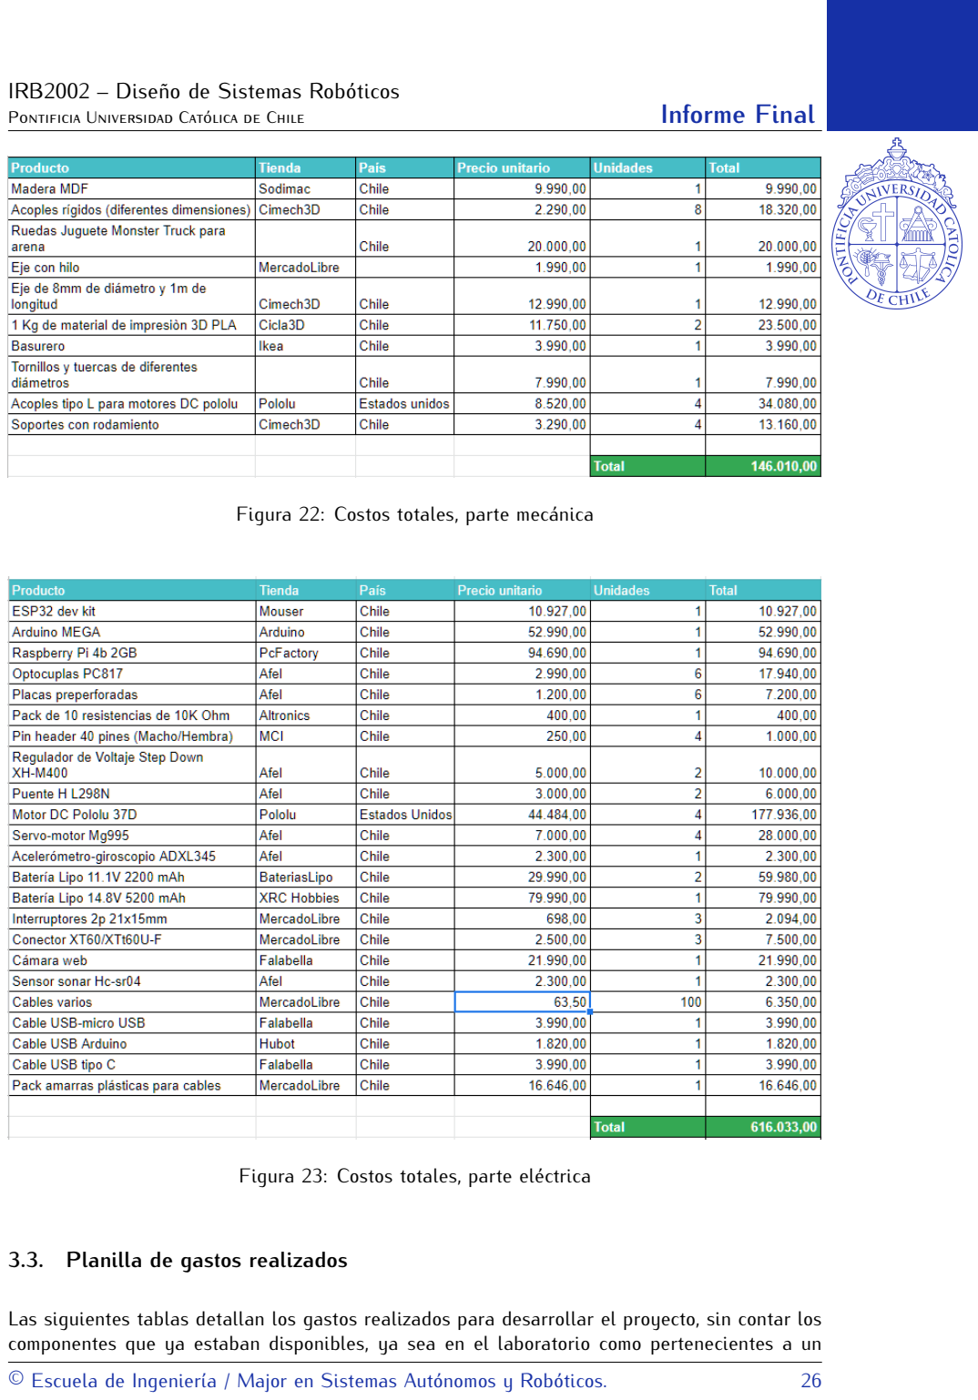
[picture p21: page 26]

Figura 22: Costos totales, parte mecánica

Figura 23: Costos totales, parte eléctrica

### 3.3. Planilla de gastos realizados

Las siguientes tablas detallan los gastos realizados para desarrollar el proyecto, sin contar los componentes que ya estaban disponibles, ya sea en el laboratorio como pertenecientes a un

© Escuela de Ingeniería / Major en Sistemas Autónomos y Robóticos. | 26

integrante del grupo, donde el costo total corresponde a $ 139.270,00 pesos chilenos:

Figura 24: Gastos totales, parte mecánica

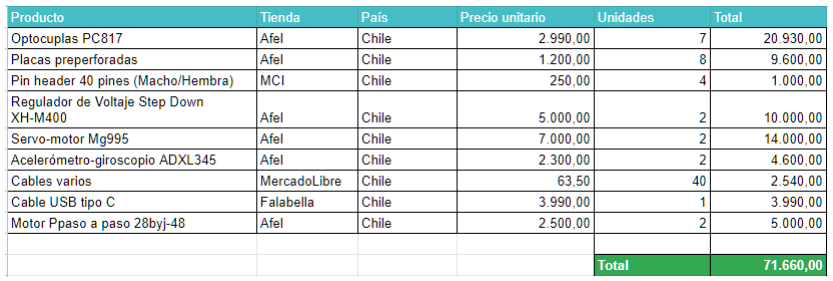
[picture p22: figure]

Figura 25: Gastos totales, parte eléctrica

## 4. Manual de Usuario

### 4.1. Hardware y software necesario

Para iniciar el manual de usuario, se presentan los componentes necesarios para construir el prototipo:

Componentes mecánicos:

- 2 planchas de madera mdf 6mm 600 x 440 mm (una para cada piso).
- 2 acoples rígidos 5mm a 8mm.
- 2 acoples rígidos 8mm a 8mm.
- 4 acoples rígidos 6mm a 8mm.
- 4 Ruedas Juguete Monster Truck para arena.
© Escuela de Ingeniería / Major en Sistemas Autónomos y Robóticos. | 27

- 4 pasadores con tuercas.
- 4 Ejes de 8mm de diámetro de 8cm de longitud.
- 2 Kg de material de impresión 3D PLA.
- 1 Basurero de 190mm de ancho.
- Tornillos y tuercas de diferentes diámetros.
- 4 Acoples tipo L para motores DC pololu.
- 4 Soportes con rodamiento.

Componentes eléctricos:

- ESP32 dev kit.
- Arduino MEGA.
- Raspberry Pi 4b.
- 6 Optocuplas PC817.
- 6 Placas preperforadas (11cm x 6cm, 6cm x 4cm, 7cm x 3cm x4)
- 12 Resistencias de 10kΩ.
- Pin header macho.
- Pin header hembra.
- 2 Reguladores de Voltaje Step Down XH-M400 8A.
- 2 Puentes H L298N.
- 4 Motores DC pololu 12V con encoder.
- 4 Servo-motores Mg995.
- 1 Acelerómetro-giroscopio ADXL345
- 2 Baterías Lipo 11.1V 2200 mAh.
- 1 Batería Lipo 14.8V 5200mAh.
- 3 Interruptores 2p 21x15mm.
- 2 Conector XT60 hembra.
- 1 Conector XT60U-F hembra.
- 1 Cámara web de resolución 640x480 píxeles.
- 1 Sensor sonar Hc-sr04.
© Escuela de Ingeniería / Major en Sistemas Autónomos y Robóticos. | 28

- Cables jumper de conexión lógica y cables de transmisión de potencia.
- 2 Cables USB tipo Arduino.
- 1 Cable USB tipo C.
- Amarres para cables

Requerimientos de software, conocimientos y herramientas computacionales

- Arduino IDE
- 1 computador con entorno de programación para python (de de preferencia VScode).
- Programa de instalación de sistemas operativos (de preferencia Rufus).
- Sistema operativo de Raspberry pi.
- Librerías de python mínimas: Numpy, Serial, Open CV, Imutils, Time, Scipy.
- Librerías de Arduino mínimas: Simple_MPU6050, Servo.

Otras herramientas necesarias

- Impresora 3D.
- Cortadora láser CNC.
- Kit de llaves Allen.
- Kit de destornilladores.
- Alicates.
- Pistola de silicona.

### 4.2. Instalación, ensamblaje y configuración

Ensamblaje:

- Cortar las planchas de madera MDF con la cortadora láser, la primera plancha es cortada según el diseño presente en el archivo P iso1_v1.dxf y la segunda debe ser según el archivo P iso2_v2.dxf. Estas piezas corresponden a los pisos uno y dos del prototipo.
- Se deben imprimir los modelos 3D para carcasas de los componentes según los archivos carcasa_motores.ipt para los motores, L298N_Case_1.0.3b.stl y L298N_Case_1.0.3c.stl para los puentes H, arduino mega case.ipt para Arduino mega y carcasa_baterias.ipt y carcasa_lippo.ipt para las baterías.
© Escuela de Ingeniería / Major en Sistemas Autónomos y Robóticos. | 29

- En la plancha correspondiente al primer piso, ensamblar los motores DC con sus respectivos soportes en forma de L. Luego, colocar un acople 6-8mm entre el eje del motor y un eje de 8mm, un rodamiento por motor y colocar dentro de su respectiva carcasa y atornillar.
- Colocar puentes H dentro de sus respectivas carcasas y atornillar entre motores (uno para dos motores).
- Con la pistola de silicona pegar tres optocuplas consiguientes a cada puente H. Las optocuplas deben ser dispuestas en paralelo desde los puentes H hacia el centro del chasis.
- Con las placas preperforadas, diseñar PCB’s descritas en el anexo 7.3 y pegar cuidadosamente en el chasis como más acomode.
- Colocar arduino mega en su carcasa y ensamblar al chasis donde más acomode (preferentemente cerca de las optocuplas).
- Unir acoples con las ruedas y ensamblar al eje de cada motor.
- Colocar baterías en sus carcasas y ensamblar en la parte trasera del motor.
- Se ensambla el brazo con los respectivos servos y sonar dentro de este según los planos del brazo presentados en el diagrama de bajo nivel.
- Se colocan los servos de la base del brazo en sus respectivas carcasas y luego se acopla la base al brazo.
- Se ensambla el brazo al chasis.

Conexiones:

- Conectar a cada batería un interruptor on-off.
- Se debe conectar a la salida de una batería cuatro cables (dos alimentaciones y dos tierras que vayan conectadas a los dos puentes H (una alimentación y una tierra para cada puente H).
- Desde los puentes H se conectan seis cables que corresponden a señales (pines lógicos), estos van conectados a las optocuplas.
- Desde las optocuplas se conectan seis cables a una PCB (disponible en el anexo 7.3). Esta pcb recibe las señales desde las optocuplas y conecta con Arduino Mega a los pines correspondientes (disponibles en diagrama de bajo nivel).
- Conectar encoders de los motores a PCB de forma que quede cómodo conectar a la ESP32.
- La ESP32 recibe los encoders, un cable de alimentación y un cable de tierra.
- Una vez hechas las conexiones y ensamblado el segundo piso, se dispone la Raspberry pi y se conecta con el Arduino Mega por comunicación serial, de esta forma podremos enviar la información al Arduino para que controle los motores.
© Escuela de Ingeniería / Major en Sistemas Autónomos y Robóticos. | 30

- Conectar cámara web a Raspberry pi por comunicación serial.

Instalación de software:

- Dirigirse al sitio web oficial (https://www.raspberrypi.com/software/operating-systems/) de Raspberry Pi para descargar el sistema operativo.
- Descargar el OS llamado "Raspberry Pi OS (64-bit)".
- Descargar Rufus desde su sitio web oficial (https://rufus.ie/es/)
- Abrir Rufus, seleccionar el sistema operativo descargado y conectar la memoria SD donde se va a realizar la partición. Iniciar el proceso de instalación.
- Luego de terminado el proceso, retirar la memoria SD e insertarla en la Raspberry Pi.
- Conectar la Raspberry Pi a un monitor por HDMI, conectar ratón y teclado. Luego, energizar la Raspberry.
- Seguir las instrucciones de instalación.
- Luego de instalado el OS, abrir un terminar y ejecutar los siguientes códigos:

$ pi p 3 i n s t a l l numpy
$ pi p 3 i n s t a l l s ci p y
$ pi p 3 i n s t a l l i m u t i l s
$ pi p 3 i n s t a l l opencv−py thon
- Transferir los archivos de extensión .py de la carpeta de códigos.
- Cargar el archivo W all2_MARK5.ino al Arduino Mega y el archivo W all2_ESP32.ino a la ESP32 a través de la IDE de Arduino.
- Conectar el Arduino Mega y la ESP32 a la Raspberry mediante conexión USB.

### 4.3. Instrucciones de uso

- Encender el interruptor que energiza la Raspberry Pi y el resto de controladores.
- Encender los interruptores que alimentan a los motores y los servos.
- Ejecutar el código ”W all2_MARK5.py”
© Escuela de Ingeniería / Major en Sistemas Autónomos y Robóticos. | 31

## 5. Análisis de resultados finales

Como se ha mencionado en secciones anteriores en el informe, el desempeño del robot en la presentación final no fue el óptimo. Es por esta razón que, a continuación, se va a dedicar una sección exclusiva que resuma todos los avances más significativos del proyecto, los objetivos logrados y no logrados que se habían planteado en este proyecto, los problemas que se tuvieron a lo largo del proyecto y sus posibles causas y un apartado de trabajo futuro que señalen todos los aspectos a mejorar del robot.

### 5.1. Experimentos realizados

Para poder verificar el cumplimiento de los objetivos planteados al inicio del proyecto se realizaron experimentos de forma modular, dando paso a pruebas de una única funcionalidad, las que permitían paso a paso demostrar el funcionamiento del robot.

Segmentación de Mascarillas

Este experimento demuestra que el controlador era capaz de detectar la presencia o no de una mascarilla y, en el caso de que efectivamente hubiese una, segmentar y ubicar en el espacio la localización de ella. La demostración se encuentra en el archivo de grabación ”demo_segmentacion.mp4”, en el que se puede observar cómo el algoritmo logra segmentar de manera exitosa la mascarilla. Como observación, se puede notar que al voltear la mascarilla, la segmentación decae en desempeño, esto se debe a que los parámetros de la segmentación son determinados de forma heurística, por lo que en este caso el rango de colores no consideró tonos demasiado blancos.

PICK-UP Estático

Este experimento demuestra el adecuado funcionamiento del protocolo de instrucciones que hacen que el brazo robótico se mueva para recoger una mascarilla. Este experimento consiste en que el robot se sitúa frente a una mascarilla. Luego, se envían la instrucción de PICK-UP para recoger la mascarilla. El video de demostración se llama ”demo_pickup.mp4”.

Orientación respecto a mascarilla segmentada

Este experimento demuestra que, en base a la segmentación de imágenes y la ubicación del objeto en la cámara, el robot envía señales a sus ruedas para orientarlo, de modo que mire directamente hacia la mascarilla. El video con la demostración corresponde a ”demo_orientacion.mp4”.

© Escuela de Ingeniería / Major en Sistemas Autónomos y Robóticos. | 32

Modo exploración

Este experimento tuvo como objetivo demostrar el protocolo de exploración implementado para WALL2. El resultado esperado es que el robot sea capaz de realizar una trayectoria cuadrada que representa el terreno a cubrir por el robot en dicho modo. El video de demostración corresponde a ”demo_trayectorias.mp4”. Como se puede apreciar en el video, el robot es capaz de mantener la trayectoria deseada, completando así el cuadrado. Sin embargo, es importante destacar que el experimento fue realizado en piso plano, por lo que no se garantiza que tenga el mismo comportamiento en la arena. Además, para demostrar que el algoritmo es robusto ante perturbaciones, el video ”demo_linea_recta.mp4” muestra al robot siguiendo una trayectoria en línea recta, mientras es perturbado con fuerzas externas. Se puede apreciar como el robot logra retornar a la trayectoria establecida luego de haber sido movido.

Modo recolección

Este experimento tuvo como objetivo demostrar que el robot, al ya haber reconocido una mascarilla, es capaz de acercarse y recogerla. Este experimento se hizo asumiendo que el robot ya se había orientado correctamente, por lo que solo debía avanzar en linea recta. El video de demostración corresponde a ”demo_recoleccion.mp4”. En él, se puede notar como el robot se detiene en el momento en que se encuentra a una distancia ideal de la mascarilla, para posteriormente ejecutar el protocolo de PICK-UP. También es posible apreciar que el robot es capaz de recoger una serie de mascarillas, siempre y cuando estas se encuentren justo al frente de él.

### 5.2. Problemas, fallas críticas y sus causas

Luego de mostrado los avances más significativos en el proyecto propuesto, es necesario describir los diferentes problemas y fallos que sucedieron a lo largo del desarrollo del proyecto, los cuales provocaron retrasos de tiempos significativos.

Diseño del chasis del robot

Una de las etapas fundamentales que se debían completar cuanto antes corresponde al diseño del chasis, dado que este debe adecuarse a todos los componentes que va a poseer el sistema. A lo largo del semestre, el proyecto pasó por diferentes iteraciones en su diseño, entre ellos abarcan eliminación o incorporación de componentes, cambios en la posición de ensamblaje al chasis, aumentos en el espacio necesario, entre otros. Esto dio como resultado que se el chasis haya tenido un total de 5 versiones diferentes, lo que implica que se gastó una cantidad no menor de tiempo en volver a manufacturar el chasis, dado que la mayoría de pruebas no se podían realizar mientras el chasis no estaba listo.

© Escuela de Ingeniería / Major en Sistemas Autónomos y Robóticos. | 33

Alineación de los ejes de los motores

Un momento crítico en el desarrollo con el proyecto fue un problema que surgió al momento de realizar el primer ensamblaje de los motores, los ejes y las ruedas. Al momento de hacer girar las ruedas en el aire (sin carga), se pudo notar que el consumo de corriente era superior a lo que se esperaba. Luego, al encender la base móvil para que se desplace en el piso, se pudo notar que los motores no eran capaces de mover el robot y que el consumo de corriente alcanzaba los límites que podía entregarla fuente de poder que los estaba alimentando en ese momento. Por esta razón, se tuvieron que suspender las pruebas hasta determinar la causa del problema y corregirlo. Al momento de desmantelar el chasis, se pudo descubrir el origen del problema, eje de la rueda se encontraba desalineado con respecto al eje del motor, lo que causaba que el eje no pudiera girar apropiadamente, obligando al motor a generar más torque del necesario para hacer girar el eje a la velocidad deseada, provocando un consumo de corriente excesivo, que repercutía en los puentes H y la fuente de alimentación. Para solucionar el problema, se tuvieron que diseñar piezas en 3D que compensaran la diferencia de alturas entre los ejes, lo cual fue una reparación que tomó aproximadamente una semana en concretarse.

Diseño del brazo robótico

Originalmente, el brazo robótico del proyecto utilizaba dos motores paso a paso 28byj-48, los cuales se encargaban de levantar el brazo completo. Acorde a los cálculos previos, estos motores eran capaces de generar el torque necesario para cumplir con su tarea. Al momento de fabricar el brazo en su totalidad, se realizó una prueba con dichos motores, para verificar su adecuado funcionamiento. Al comenzar la prueba, se observó que los motores no eran capaces de levantar el brazo. Para solventar rápidamente el problema, la base del brazo fue rediseñada, sustituyendo los motores paso a paso por servo-motores Mg995, los cuales eran capaces de generar más torque que los motores anteriores. De esta forma, se logra obtener el diseño final presentado anteriormente en el diagrama de bajo nivel. Dicho cambio detuvo el desarrollo por lo menos la mitad de una semana.

Pruebas de tracción en la arena

Una de las principales fallas en el diseño final es que, al momento de probar el robot en arena en la presentación final, el robot no era capaz de desplazarse en el terreno. La principal razón de este fallo fue la falta de pruebas en el terreno real, gran parte de los experimentos en los que se probaba la base móvil fueron realizados dentro del laboratorio, en los que se cuenta con piso plazo, sin mayores irregularidades en el terreno, por lo que gran parte del diseño fue probado y ajustado en este ambiente y no en el real. Dentro de las pocas pruebas que se realizaron en arena, existe una en la que el robot lograba efectivamente desplazarse en el terreno. Sin embargo, en esa ocasión, se utilizó una versión incompleta del robot, el cual contaba solamente con los motores y las baterías instalados. Por lo tanto, este experimento, a pesar de ser exitoso, no considera el peso extra que tienen el resto de componentes que no habían sido agregados aún. Por otro lado, la forma del chasis final difiere en varios aspectos del chasis utilizado en ese experimento, lo que implica que el cambio en la geometría pudo haber perjudicado también en la tracción que genera la base móvil.

© Escuela de Ingeniería / Major en Sistemas Autónomos y Robóticos. | 34

Sobrecalentamiento de un puente H

Los puentes H son los drivers que nos permiten controlar la dirección y velocidad de giro de las ruedas de WALL2. Durante las pruebas realizadas nos dimos cuenta de que el driver correspondiente a los motores traseros se sobre calentaba llegando a temperaturas muy superiores al driver correspondiente a los motores delanteros. Este problema terminó finalmente quemando 2 veces el puente H de las ruedas traseras.

Como grupo, analizando las posibles causas de este problema, llegamos a estas 2 posibles situaciones que generaron este problema:

- Desajuste de las ruedas traseras

Al ensamblar el diseño final de WALL2 fijamos los motores al chasis y los cubrimos con sus respectivas protecciones. A medida que hicimos pruebas y hacíamos navegar al robot nunca reajustamos ni apretamos los tornillos de los motores. Esto resultó en que los motores traseros se soltaran, permitiendo juego entre los motores y el chasis, desalineando el eje del motor con el rodamiento que iba a las ruedas y generando peaks de corriente en dichos motores y sobre calentando de sobremanera el puente H, llegando a quemarlo.

- Regulador de voltaje del puente H en mal estado

Al revisar el puente H quemado nos dimos cuenta que el regulador de voltaje interno que tienen estos drivers estaba quemado, por lo que la salida que debiese ser de 5V era de 12V , generando que el circuito lógico del driver fuese alimentado con dicho voltaje, pudiendo generar el aumento de temperatura y posterior quema del chip.

Daño en la ESP32

El último problema que nos surgió fue que al momento de conectar la ESP32 de forma definitiva, nos dimos cuenta de que su temperatura era extremadamente alta y que se había quemado.

Como grupo analizamos las posibles causas y la única conclusión posible a la que llegamos fue que a través de la conexión de las tierras haya existido una corriente parásita proveniente de la alimentación de los servomotores que haya producido que la ESP32 se quemara. Esta corriente parásita se pudo haber dado ya que la alimentación de los servomotores y de los encoders vienen de un regulador de 7.2V , y al ser la ESP32 el microcontrolador que lee los encoders la tierra de todo el circuito debe ser común.

### 5.3. Objetivos cumplidos y no cumplidos

Para este proyecto se plantearon 4 objetivos específicos los cuales, con el resultado final de nuestro robot, pudimos evaluar si fueron cumplidos o no. Estos son:

- Diseñar e implementar base móvil con sistema de tracción capaz de movilizarse y maniobrar en arena sin dificultades.
© Escuela de Ingeniería / Major en Sistemas Autónomos y Robóticos. | 35

- Implementar sistema de pick-up y almacenamiento de mascarillas.
- Desarrollar un algoritmo de clasificación y detección de mascarillas con una visibilidad sobre la arena de un 50% para lograr su segregación y posterior recolección.
- Desarrollar protocolo de navegación sobre zona de la playa a limpiar.

Respecto al primer objetivo, sí fuimos capaces de implementar una base móvil con tracción, el cual se desplaza de buena manera en un suelo plano y sin muchas irregularidades. Ahora bien, hemos fallado en que este sistema de tracción sea apto para trasladarse en la arena. Esto se puede deber a varios factores. El primero de ellos es el gran peso que tuvo el robot en su diseño final. A medida en que se fue avanzando en su constricción, poco a poco se tuvo que ir aumentando su tamaño debido a que era necesario agregar nuevos componentes eléctricos, como, por ejemplo, las optocuplas PC817 o los reguladores de voltaje. Otro factor importante fue que no se hicieron pruebas suficientes en la arena cuando éste ya se encontraba con todo su peso final, lo que provocó que el robot se quedara atascado en la misma arena.

Por otro lado, el segundo objetivo se logró cumplir exitosamente. Luego de mucho tiempo de diseño del brazo robótico e intentar distintas maneras de afirmarlo al chasis, el brazo funciona de manera rápida y fluida, y es capaz de dejar caer las mascarillas en un recipiente destinado a su almacenamiento.

Ahora bien, sobre el tercer objetivo, hemos decidido que para detectar una mascarilla sea una segmentación por color, por lo que siempre que se vea de manera clara una parte de la mascarilla que se encuentre dentro del rango de los colores escogidos, entonces el algoritmo reconocerá a dicha mascarilla, lo que permite segmentar mascarillas que tengan una visibilidad menor al 50% sobre la arena. Pero el problema con esto es que si el robot se encuentra con una mascarilla que se vea por el otro lado, entonces la cámara no la reconocerá debido a su color. Por lo tanto, este objetivo no es el adecuado para describir realmente lo que terminó siendo el proyecto final.

Por último, respecto al último objetivo, sí se logró desarrollar un protocolo de navegación, y este protocolo utilizaba la información que entregaba los encoders de los motores DC para calcular la distancia recorrida, pero como se mencionó anteriormente, la ESP32 la cual estaba encargada de leer dichos encoders se quemó. Por lo que, debido a esto debimos cambiar el protocolo basándonos en el tiempo de ejecución del algoritmo, lo que no es recomendable, ya que puede haber casos en que el robot no avance y el tiempo sigue avanzando, afectando así el momento en que cambias las instrucciones que reciben los motores DC. Por lo tanto, sí logramos realizar un protocolo de navegación, pero éste tuvo que cambiarse para adaptarse a la situación que se vivió.

### 5.4. Mejoras al proyecto

Dado todo lo que se mencionó con anterioridad, es claro que se pueden hacer mejoras al proyecto. Primero, cambiar el sistema de tracción por uno en donde haya reducción con el fin de generar mejor tracción en la arena. Segundo, se debe mejorar la selección de ruedas, dado que estas

© Escuela de Ingeniería / Major en Sistemas Autónomos y Robóticos. | 36

sufrieron complejidades al momento de desplazarse en arena, y además que sean capaces de traccionar considerando el peso final del robot. Por otro lado, es necesario implementar mayor protección a los componentes eléctricos, ya sea cubriendo los componentes con carcasas más herméticas o construyendo un chasis cerrado que impida el paso de material granulado cerca de los componentes.

Respecto a las mejoras eléctricas es fuertemente recomendable hacer las PCB’s en una enrutadora, ya que es fácil que se produzcan cortocircuitos haciéndolas a mano como nos ocurrió durante el desarrollo del proyecto. Es necesario también la disposición de una Raspberry de mayor capacidad, esto dado que el robot requiere tomar datos en tiempo real para poder tomar decisiones.

En cuanto a las mejoras de software, se mencionó el uso de un algoritmo de segmentación por colores. Este método de reconocimiento puede ser mucho más preciso si se hace uso de redes neuronales convolucionales, las cuales darían al robot la posibilidad de recoger más de un tipo de mascarillas.

Por último, sabiendo que se tienen todos los componentes eléctricos y mecánicos necesarios, se debe intentar minimizar el peso del chasis para así realizar el menor esfuerzo mecánico posible y poder facilitar su traslación sobre la arena.

© Escuela de Ingeniería / Major en Sistemas Autónomos y Robóticos. | 37

## 6. Referencias

[1] Residuos Profesional, 2021. LOS RESIDUOS DE MASCARILLAS AUMENTARON UN 9.000% ENTRE MARZO Y OCTUBRE DE 2020. Disponible en el siguiente LINK (https://www.residuosprofesional.com/residuos-mascarillas-aumentaron-2020/)

[2]International Organization for Standardization. (2016). Robotics — Performance criteria and related test methods for service robots — Part 1: Locomotion for wheeled robots (ISO Standard No. 18646-1:2016). Disponible en el siguiente LINK (https://www.iso.org/contents/data/standard/06/31/63127.html)

[3]International Organization for Standardization. (2021). Robotics — Performance criteria and related test methods for service robots — Part 3: Manipulation (ISO Standard No. 18646-3:2021). Disponible en el siguiente LINK (https://www.iso.org/standard/73591.html)

[4] Rainford Solutions, 2022. What is an IP Rating?: Ingress Protection. Disponible en el siguiente LINK (https://rainfordsolutions.com/products/ingress-protection-ip-rated-enclosures/ip-enclosure-ratings-standards-explained/)
[5] International Organization for Standardization. (2017). Mobile robots — Vocabulary (ISO Standard No. 19649:2017). Disponible en el siguiente LINK (https://www.iso.org/standard/65658.html)
[6] Raspberry Pi, 2019. Raspberry Pi 4 model B, no.1. Disponible en el siguiente LINK (https://www.google.com/url?rct=j&q=&esrc=s&cd=&cad=rja&uact=8)
[7] Arduino, 2022. Arduino® MEGA 2560 Rev3. Disponible en el siguiente LINK (https://docs.arduino.cc/hardware/mega-2560)
[8] Espressif Systems. (2019). ESP32 Series. Disponible en el siguiente LINK (https://www.alldatasheet.com/view.jsp?Searchword=Esp32%20datasheet)
[9] Electronic Components Group SHARP Corporation, 1995. Device specification for Photocoupler model no. PC817. Disponible en el siguiente LINK (https://www.alldatasheet.com/datasheet-pdf/pdf/43368/SHARP/PC817.html)
[10] Pololu, 2022. 37D Metal Gearmotors. Disponible en el siguiente LINK (https://www.pololu.com/file/0J1736/pololu-37d-metal-gearmotors-rev-1-2.pdf)
[11] Marlin P. Jonse & Assoc., Inc. MG995 High Speed Servo Actuator. Disponible en el siguiente LINK (https://www.alldatasheet.com/view.jsp?Searchword=Mg995%20datasheet)
[12] STMicroelectronics, 2000. DUAL FULL-BRIDGE DRIVER.Disponible en el siguiente LINK (https://pdf1.alldatasheet.com/datasheet-pdf/view/22440/STMICROELECTRONICS/L298N.html)
[13] InvenSense. MPU-6000and MPU-6050 Product Specification.Disponible en el siguiente LINK (https://pdf1.alldatasheet.com/datasheet-pdf/view/517744/ETC1/MPU-6050.html)
© Escuela de Ingeniería / Major en Sistemas Autónomos y Robóticos. | 38

## 7. Anexos

### 7.1. Archivos

En la carpeta Archivos/ Se encuentran las siguientes carpetas:

- Brazo/: Contiene todos los modelos necesarios para construir el brazo robótico.
- Carcasas/: Contiene los modelos de las protecciones de los componentes.
- Codigos/: Contiene los codigos que deben ser cargados a la Raspberry Pi, Arduino Mega y ESP32.
- DiagramaP CB/: Contiene los diagramas que se utilizaron para fabricar las tarjetas de interconexión.
- P isos/: Contiene los archivos .dxf de corte laser para fabricar los pisos de la base móvil.
- V ideos/: Contiene los videos de demostración, corresponden a los mismo que se enviaron por correo.

### 7.2. Cálculo de torque de los motores de las ruedas

En este caso, se asume que el robot diseñado se puede aproximar a una caja de masa uniformemente distribuida y masa total M, de modo que su centro de masa se encuentra en el centro geométrico de la caja. Luego, se define F como la fuerza de tracción que ejercen los motores para que el robot se mueva. Para adecuar mejor manera el robot al terreno en el cual va a desplazarse, se considera que el robot se encuentra en un plano inclinado con inclinación α y coeficiente de roce entre las ruedas y el suelo µ, de esta forma, se pretende simular los casos en que el robot deba desplazarse cuesta arriba, donde los motores deberán ejercer mayor torque. Por otro lado, el coeficiente de roce será utilizado para simular la resistencia que va a ejercer la arena en las ruedas del robot.

Por lo tanto, aplicando la ley de sumas de fuerzas, se tiene que:

© Escuela de Ingeniería / Major en Sistemas Autónomos y Robóticos. | 39

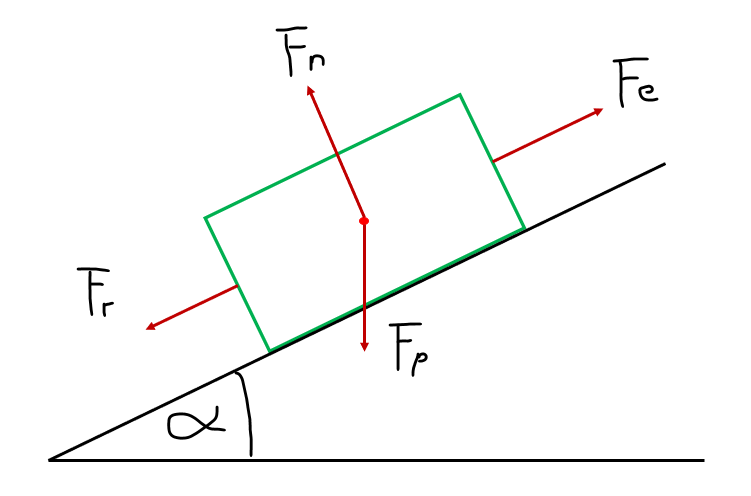
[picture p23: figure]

Figura 26: Diagrama de fuerzas del robot simplificado

XF = M a

F − F r − MgCos(

π
2

− α) = M a

F = M a + Fr + MgCos(

π
2

− α)

F = M a + MgµCos(α) + Sin(α)

Luego, el torque total que deben ejercer las ruedas del robot se calcula como:

τ = RF
τ = R(M a + MgµCos(α) + Sin(α))

Donde R corresponde al radio de las ruedas del robot. Para calcular el torque necesario, solo hace falta conocer el valor de la aceleración a. Para esto, se considera un perfil de velocidades trapezoidal, de velocidad máxima Vmax, y tiempo de aceleración de trise. Entonces, la aceleración se calcula como:

a =

Vmax

trise
Finalmente, al considerar 4 motores para las ruedas del robot, el torque y velocidad angular necesario en los motores se pueden escribir como:

τ =

R
4

(M

Vmax

trise

+ MgµCos(α) + Sin(α))

ω =

Vmax
R
© Escuela de Ingeniería / Major en Sistemas Autónomos y Robóticos. | 40

Cálculo de torque de los motores del brazo

En este caso, el brazo robótico se puede aproximar como dos objetos de masa uniformemente distribuida: un cilindro de largo L y masa M1, el cual tiene acoplado en uno de sus extremos una esfera de radio r y masa M2, que representa el sistema de pick-up. En este caso, el torque se puede escribir como:

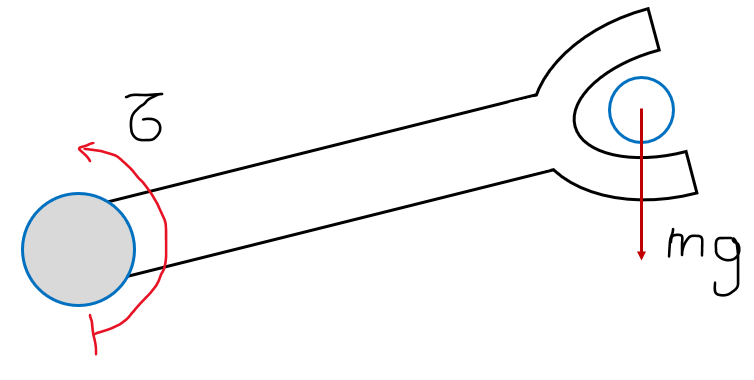
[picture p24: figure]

Figura 27: Diagrama de fuerzas del brazo simplificado

τ = Itω˙

Donde el momento de inercia se escribe como:

It = I1 + I2 + M2(L + r)

2

I1 =

1
3

M1L

2

I2 = M2r

2

Luego, la aceleración angular se calcula considerando un perfil de velocidades trapezoidal al igual que en el caso anterior, de modo que el cálculo es análogo:

ω˙ =

ωmax

trise

Finalmente:

τ =

ωmax

trise

∗ (

1
3

M1L

2 + M2r

2 + M2(L + r)

2
)

Cálculo de torque de los motores del brazo

En este caso, el cálculo es similar al caso anterior, con la diferencia en que no se considera el brazo, solamente la esfera que representa el sistema de pick-up, por lo tanto:

ωmax

trise

∗ (M2r

2 + M2r

2
)
© Escuela de Ingeniería / Major en Sistemas Autónomos y Robóticos. | 41

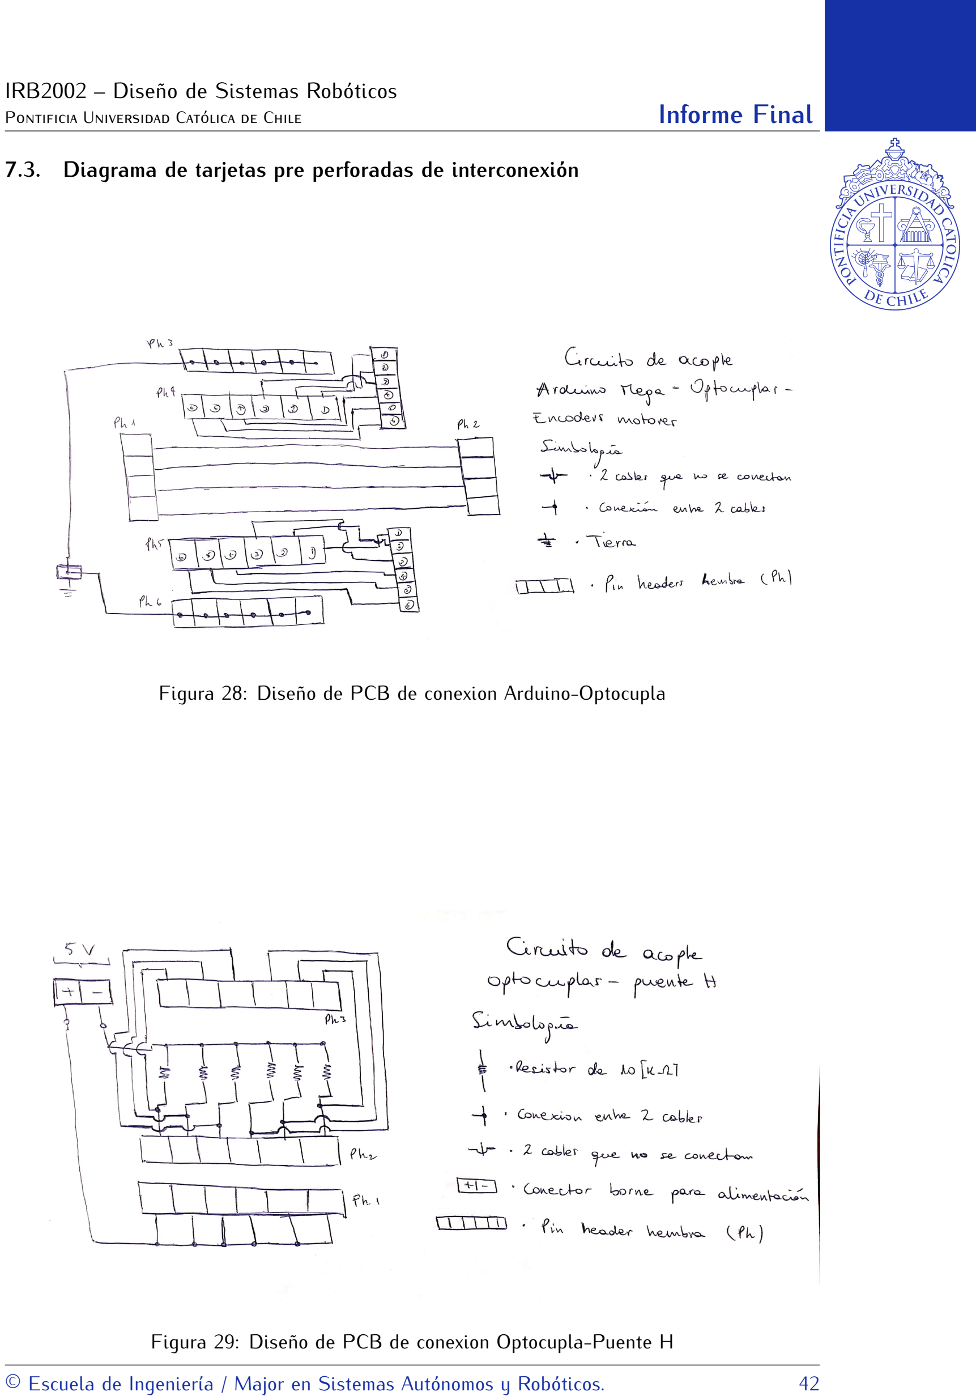
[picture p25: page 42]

### 7.3. Diagrama de tarjetas pre perforadas de interconexión

Figura 28: Diseño de PCB de conexion Arduino-Optocupla

Figura 29: Diseño de PCB de conexion Optocupla-Puente H

© Escuela de Ingeniería / Major en Sistemas Autónomos y Robóticos. | 42

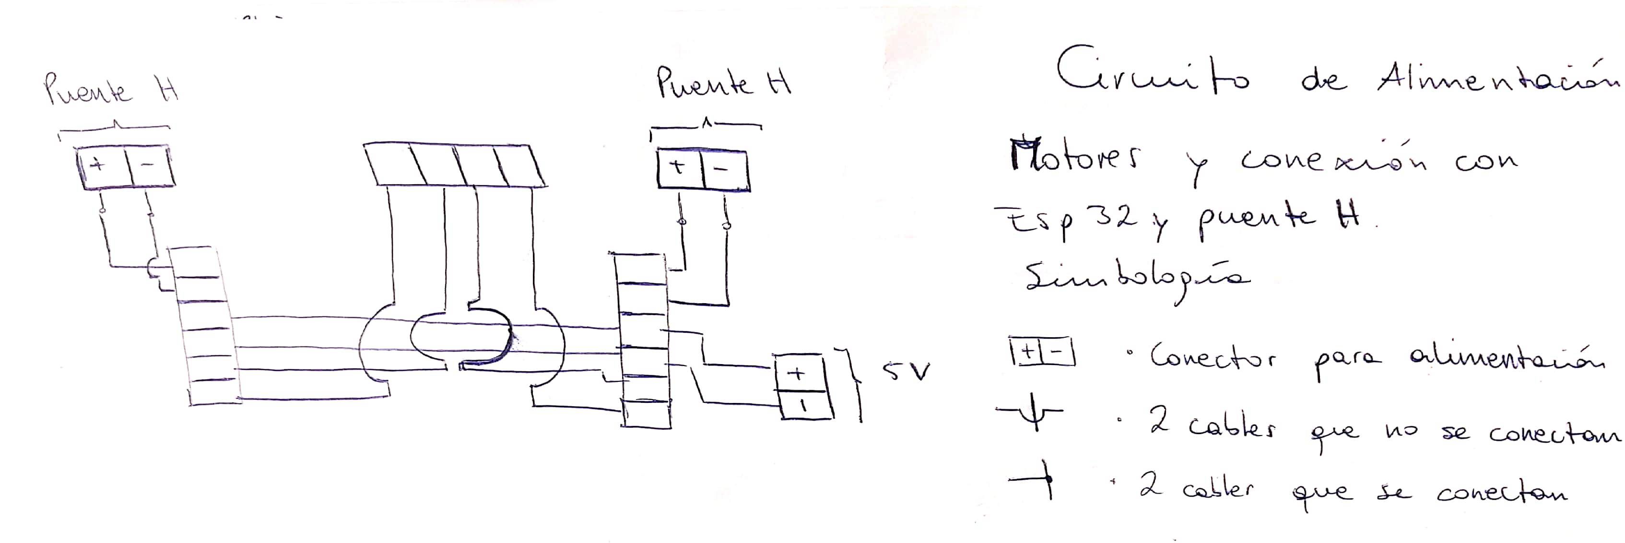
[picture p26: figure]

Figura 30: Diseño de PCB de conexion de motores

© Escuela de Ingeniería / Major en Sistemas Autónomos y Robóticos. | 43



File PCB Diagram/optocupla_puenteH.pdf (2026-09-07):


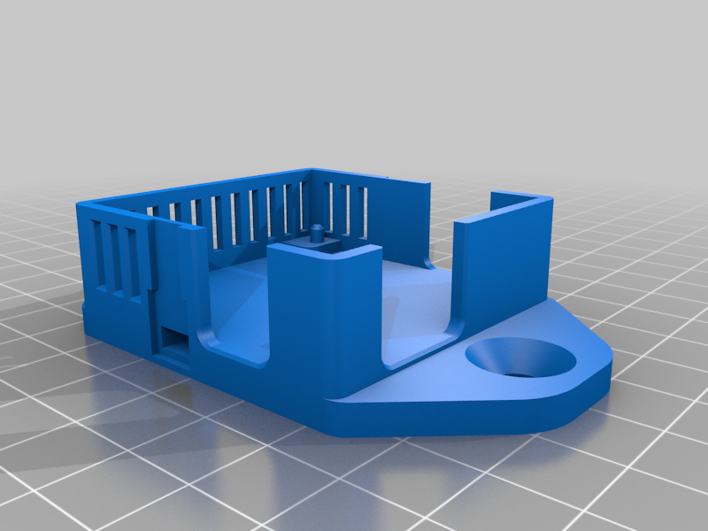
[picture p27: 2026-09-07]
Casing/3328541_L298N_Case_with_Zip-Tie_closure_and_Screw_holes_for_placement/images/L298N_Case_1.0.3b.png

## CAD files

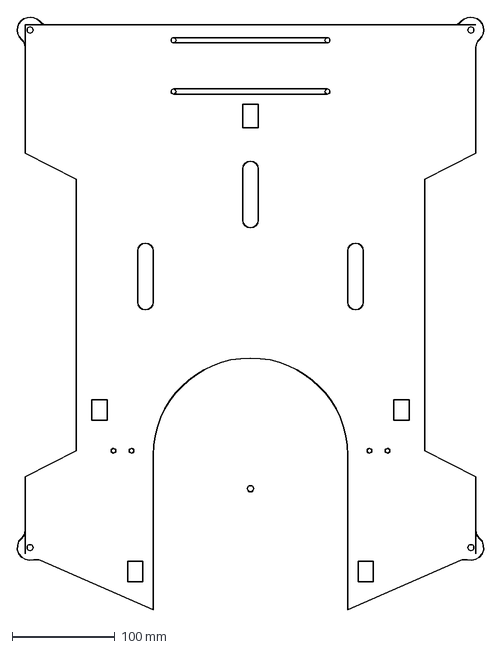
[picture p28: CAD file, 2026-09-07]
Levels/Piso2_v2.dxf
457.5 x 578.6 mm

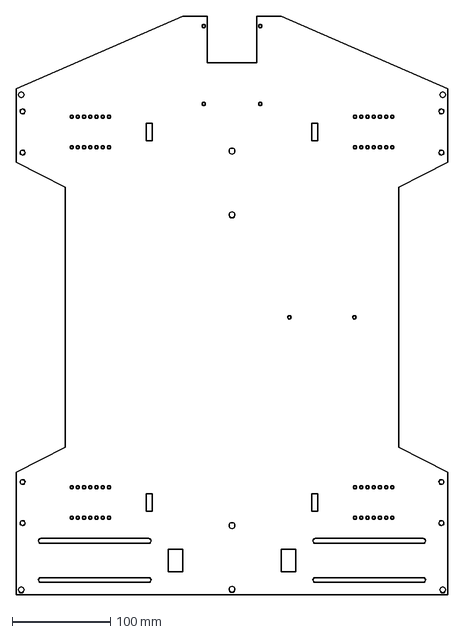
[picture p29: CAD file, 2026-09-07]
Levels/Piso1_v1.dxf
440.0 x 590.0 mm

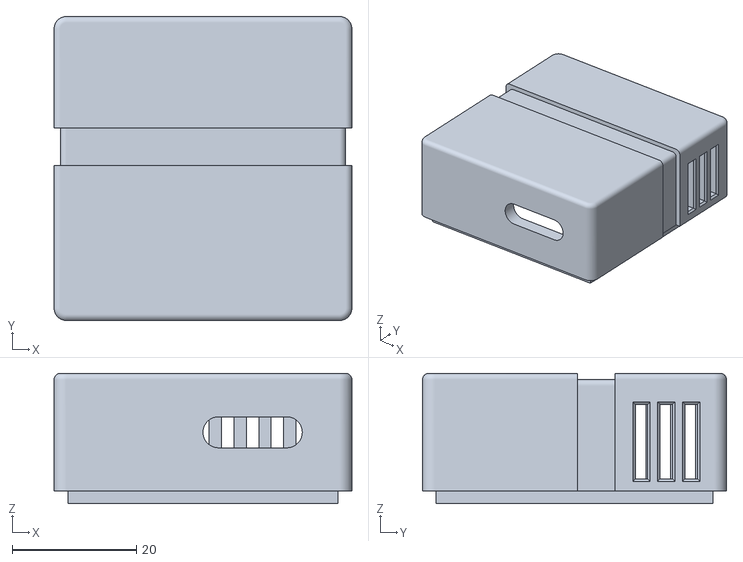
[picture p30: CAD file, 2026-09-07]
Casing/3328541_L298N_Case_with_Zip-Tie_closure_and_Screw_holes_for_placement/files/L298N_Case_1.0.3c.stl
48.0 x 49.0 x 21.0

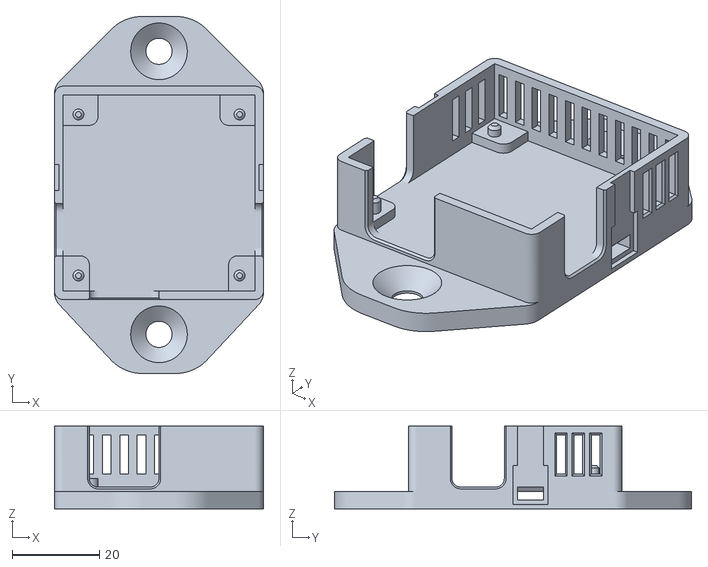
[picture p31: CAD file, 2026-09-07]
Casing/3328541_L298N_Case_with_Zip-Tie_closure_and_Screw_holes_for_placement/files/L298N_Case_1.0.3b.stl
48.0 x 82.0 x 19.0

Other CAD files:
Arm/Gripper.iam
Arm/OldVersions/Gripper.0027.iam
Arm/OldVersions/NEMA_bottom_case.0004.ipt
Arm/OldVersions/NEMA_top_case.0008.ipt
Arm/OldVersions/Nema.0002.ipt
Arm/OldVersions/Stepper motor ASSEMBLY.0001.iam
Arm/OldVersions/TOWER PRO MG-995, ANALOG SERVO v9.0012.iam
Arm/OldVersions/Ultra Sonic Sensor.0002.ipt
Arm/OldVersions/Worm Gear1.0016.ipt
Arm/OldVersions/Worm1.0008.ipt
Arm/OldVersions/acople_1.0001.ipt
Arm/OldVersions/acople_2.0002.ipt
Arm/OldVersions/acople_3.0003.ipt
Arm/OldVersions/acople_3.0004.ipt
Arm/OldVersions/acople_4.0006.ipt
Arm/OldVersions/acople_acr.0002.ipt
Arm/OldVersions/acople_stepper.0004.ipt
Arm/OldVersions/agarre_derecha.0001.ipt
Arm/OldVersions/agarre_derecha.0003.ipt
Arm/OldVersions/agarre_izquierda.0002.ipt
Arm/OldVersions/antebrazo.0010.ipt
Arm/OldVersions/base_servos.0004.ipt
Arm/OldVersions/bottom_case.0001.ipt
Arm/OldVersions/carcasa_giroscopio.0003.ipt
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

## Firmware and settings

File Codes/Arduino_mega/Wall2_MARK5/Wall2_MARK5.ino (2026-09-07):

/*
  REFERENCIAS:

    -Codigo basado en el programa de ejemplo incluido en la libreria Simple_MPU6050
    https://www.youtube.com/c/BitwiseAr
    Autor: bitwiseAr  

*/

#include "Simple_MPU6050.h"					// incluye libreria Simple_MPU6050
#include <Servo.h>                  // Libreria para los servo

//----------------- PARÁMETROS MPU ------------------
#define MPU6050_ADDRESS_AD0_LOW     0x68			// direccion I2C con AD0 en LOW o sin conexion
#define MPU6050_ADDRESS_AD0_HIGH    0x69			// direccion I2C con AD0 en HIGH
#define MPU6050_DEFAULT_ADDRESS     MPU6050_ADDRESS_AD0_LOW	// por defecto AD0 en LOW

//----------------- PARÁMETROS SERVOS -----------------------
#define SERVO_1 3
#define SERVO_2 4
#define SERVO_3 5
#define SERVO_4 6

//------------------ MOTORES DC ---------------------
int ENB_TL = 8;
int IN3_TL = 24;
int IN4_TL = 22;

int IN1_TR = 25;
int IN2_TR = 23;
int ENA_TR = 9;

int ENB_BR = 10;
int IN3_BR = 30;
int IN4_BR = 32;

int IN1_BL = 31;
int IN2_BL = 33;
int ENA_BL = 11;

//---------- RECEPCION DE DATOS ------------
int number = 0;                   // Variable para guardar el int que se recibe
String inputString = "";          // Almacena la cadena de datos recibida
String numString = "";            // Almacena la cadena de datos recibida para números
bool stringComplete = false;

//----------- VARIABLES SERVOMOTORES -----------
int pulsoMinimo = 580;    // Duración en microsegundos del pulso para girar 0º
int pulsoMaximo = 2500;   // Duración en microsegundos del pulso para girar 180º
int pulsoMaximo2 = 3460;   // Duración en microsegundos del pulso para girar 270º
int a_g = 110;           // Variable para guardar el angulo que deseamos de giro en la garra
int a_m = 180;           // Variable para guardar el angulo que deseamos de giro en la muñeca
int a_b = 100;           // Variable para guardar el angulo que deseamos de giro en la base
int a_ant_g = 110;           // Variable para guardar el angulo anterior que deseamos de giro en la garra
int a_ant_m = 180;           // Variable para guardar el angulo anterior que deseamos de giro en la muñeca
int a_ant_b = 100;           // Variable para guardar el angulo anterior que deseamos de giro en la base
Servo servo1;
Servo servo2;
Servo servo3;
Servo servo4;

//------------ GIROSCOPIO ------------
Simple_MPU6050 mpu;				// crea objeto con nombre mpu
// ENABLE_MPU_OVERFLOW_PROTECTION();		// activa proteccion, ya no se requiere

#define OFFSETS  2610,   -2678,     850,     159,      36,      41  // Colocar valores personalizados

#define spamtimer(t) for (static uint32_t SpamTimer; (uint32_t)(millis() - SpamTimer) >= (t); SpamTimer = millis())
// spamtimer funcion para generar demora al escribir en monitor serie sin usar delay()

#define printfloatx(Name,Variable,Spaces,Precision,EndTxt) print(Name); {char S[(Spaces + Precision + 3)];Serial.print(F(" ")); Serial.print(dtostrf((float)Variable,Spaces,Precision ,S));}Serial.print(EndTxt);
// printfloatx funcion para mostrar en monitor serie datos para evitar el uso se multiples print()

// mostrar_valores funcion que es llamada cada vez que hay datos disponibles desde el sensor
void mostrar_valores (int16_t *gyro, int16_t *accel, int32_t *quat, uint32_t *timestamp) {	
  uint8_t SpamDelay = 100;			// demora para escribir en monitor serie de 100 mseg
  Quaternion q;					// variable necesaria para calculos posteriores
  VectorFloat gravity;				// variable necesaria para calculos posteriores
  float ypr[3] = { 0, 0, 0 };			// array para almacenar valores de yaw, pitch, roll
  float xyz[3] = { 0, 0, 0 };			// array para almacenar valores convertidos a grados de yaw, pitch, roll
  spamtimer(SpamDelay) {			// si han transcurrido al menos 100 mseg entonces proceder
    mpu.GetQuaternion(&q, quat);		// funcion para obtener valor para calculo posterior
    mpu.GetGravity(&gravity, &q);		// funcion para obtener valor para calculo posterior
    mpu.GetYawPitchRoll(ypr, &q, &gravity);	// funcion obtiene valores de yaw, ptich, roll
    mpu.ConvertToDegrees(ypr, xyz);		// funcion convierte a grados sexagesimales
    Serial.print("YAW: ");
    Serial.println(xyz[0]);
  }
}

void setup() {
  uint8_t val;
#if I2CDEV_IMPLEMENTATION == I2CDEV_ARDUINO_WIRE	// activacion de bus I2C a 400 Khz
  Wire.begin();
  Wire.setClock(400000);
#elif I2CDEV_IMPLEMENTATION == I2CDEV_BUILTIN_FASTWIRE
  Fastwire::setup(400, true);
#endif
  
  Serial.begin(115200);			// inicializacion de monitor serie a 115200 bps
  while (!Serial); 			// espera a enumeracion en caso de modelos con USB nativo
  Serial.println(F("Iniciando sensor MPU6050"));		// muestra texto estatico
  mpu.SetAddress(MPU6050_ADDRESS_AD0_LOW).load_DMP_Image(OFFSETS);	// inicializacion de sensor

  mpu.on_FIFO(mostrar_valores);		// llamado a funcion mostrar_valores si memoria FIFO tiene valores

  pinMode (ENB_TL, OUTPUT);
  pinMode (IN3_TL, OUTPUT);
  pinMode (IN4_TL, OUTPUT);

  pinMode (IN1_TR, OUTPUT);
  pinMode (IN2_TR, OUTPUT);
  pinMode (ENA_TR, OUTPUT);

  pinMode (ENB_BR, OUTPUT);
  pinMode (IN3_BR, OUTPUT);
  pinMode (IN4_BR, OUTPUT);

  pinMode (IN1_BL, OUTPUT);
  pinMode (IN2_BL, OUTPUT);
  pinMode (ENA_BL, OUTPUT);

  servo1.attach(SERVO_1, pulsoMinimo, pulsoMaximo);
  servo2.attach(SERVO_2, pulsoMinimo, pulsoMaximo);
  servo3.attach(SERVO_3, pulsoMinimo, pulsoMaximo2);
  servo4.attach(SERVO_4, pulsoMinimo, pulsoMaximo2);
  Serial.begin(115200);

  Serial.println("Llevando al brazo a posición inicial");
  servo1.write(a_g);
  servo2.write(a_m);
  servo3.write(a_b);
  servo4.write(180 - a_b);
  inputString.reserve(200);
}

void loop()
{
  mpu.dmp_read_fifo();

  if (stringComplete) {//El comando fue recibido, procedemos a compararlo
    
    if (inputString.equals("PICK")){
      setMuneca(140);
      setBase(160);
      setGripper(5);
      setBase(80);
      setMuneca(45);
      setGripper(120);
      setMuneca(75);
      setMuneca(45);
      setMuneca(180);
      setBase(80);
      setBase(100);
      setGripper(120);
    }
    else if (inputString.equals("AJUSTARCAMARA")){
      setMuneca(180);
      setBase(125);
    }
    else if (inputString.equals("RESET")){
      void(* resetSoftware)(void) = 0;
    }
    else if (inputString.equals("SETLEFT")){
      setBLspeed(number);
      setTLspeed(number);
    }
    else if (inputString.equals("SETRIGHT")){
      setBRspeed(number);
      setTRspeed(number);
    }
    else if (inputString.equals("SETVEL")){
      setBLspeed(number);
      setTLspeed(number);
      setBRspeed(number);
      setTRspeed(number);
    }

    number = 0;                   
    inputString = ""; 
    numString = ""; 
    stringComplete = false;
  }
}		

//------------- FUNCION DE RECEPCION DE INFORMACION ------------
void serialEvent() {
  
  while (Serial.available()) {//Mientras tengamos caracteres disponibles en el buffer
    char inChar = (char)Serial.read();//Leemos el siguiente caracter
    if (inChar == '\n') {//Si el caracter recibido corresponde a un salto de línea
      stringComplete = true;//Levantamos la bandera 
    }
    else{//Si el caracter recibido no corresponde a un salto de línea
      if (isAlpha(inChar))
      {
        inputString += inChar;
      }
      else
      {
        numString += inChar;
      }
    }
  }
  if (numString.length()>1 && stringComplete)
  {
    number = numString.toInt();   // Convierte Cadena de caracteres a Enteros
    delay(5);
  }
}


//------------- FUNCIONES MOTORES TOP ---------------
void setTLspeed(int vel)
{
  if (vel < 0){
    digitalWrite (IN3_TL, HIGH);
    digitalWrite (IN4_TL, LOW);
  }
  else {
    digitalWrite (IN3_TL, LOW);
    digitalWrite (IN4_TL, HIGH);
    }
  analogWrite (ENB_TL, abs(vel));
}

void setTRspeed(int vel)
{  
  if (vel < 0){
    digitalWrite (IN1_TR, HIGH);
    digitalWrite (IN2_TR, LOW);
  }
  else {
    digitalWrite (IN1_TR, LOW);
    digitalWrite (IN2_TR, HIGH);
    }
  analogWrite (ENA_TR, abs(vel));
}

//------------- FUNCIONES MOTORES BOTTOM ---------------

void setBLspeed(int vel)
{
  if (vel < 0)
  {
    digitalWrite (IN1_BL, HIGH);
    digitalWrite (IN2_BL, LOW);
  }
  else 
  {
    digitalWrite (IN1_BL, LOW);
    digitalWrite (IN2_BL, HIGH);
  }
  analogWrite (ENA_BL, abs(vel));
}

void setBRspeed(int vel)
{
  if (vel < 0)
  {
    digitalWrite (IN3_BR, LOW);
    digitalWrite (IN4_BR, HIGH);
  }
  else
  {
    digitalWrite (IN3_BR, HIGH);
    digitalWrite (IN4_BR, LOW);
  }
  analogWrite (ENB_BR, abs(vel));
}
//------------- FUNCIONES SERVO PICK ---------------
void setGripper(int ang)
{
  a_g = ang;
  if(a_g > a_ant_g)
  {
    for(int angulo = a_ant_g; angulo <= a_g; angulo++)
    {
      servo1.write(angulo);
      delay(15);
    }
  }
  else if(a_g < a_ant_g)
  {
    for(int angulo = a_ant_g; angulo >= a_g; angulo--)
    {
      servo1.write(angulo);
      delay(15);
    }
  }
  a_ant_g = a_g;
}

void setMuneca(int ang)
{
  a_m = ang;
    if(a_m > a_ant_m)
    {
      for(int angulo = a_ant_m; angulo <= a_m; angulo++)
      {
        servo2.write(angulo);
        delay(15);
      }
    }
    else if(a_m < a_ant_m)
    {
      for(int angulo = a_ant_m; angulo >= a_m; angulo--)
      {
        servo2.write(angulo);
        delay(15);
      }
    }
    a_ant_m = a_m;
}

void setBase(int ang)
{
   a_b = ang;
    if(a_b > a_ant_b)
    {
      for(int angulo = a_ant_b; angulo <= a_b; angulo++)
      {
        servo3.write(angulo);
        servo4.write(180 - angulo);
        delay(15);
      }
    }
    else if(a_b < a_ant_b)
    {
      for(int angulo = a_ant_b; angulo >= a_b; angulo--)
      {
        servo3.write(angulo);
        servo4.write(180 - angulo);
        delay(15);
      }
    }
    a_ant_b = a_b;
}

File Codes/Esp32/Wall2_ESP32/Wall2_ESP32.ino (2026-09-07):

//------------------ DEFINICIÓN PINES MOTORES ----------------
// MOTOR 1
#define ENCODER_A0  21  // cable amarillo pololu
#define ENCODER_B0  22  // cable blanco pololu  //cable azul va a 5-12V, cable verde y negro a tierra, cable rojo 12V 

// MOTOR 2
#define ENCODER_A1 35  // cable amarillo pololu
#define ENCODER_B1 34   // cable blanco pololu  //cable azul va a 5-12V, cable verde y negro a tierra, cable rojo 12V 

// MOTOR 3
#define ENCODER_A2 15  // cable amarillo pololu
#define ENCODER_B2 2   // cable blanco pololu  //cable azul va a 5-12V, cable verde y negro a tierra, cable rojo 12V 

// MOTOR 4
#define ENCODER_A3 19  // cable amarillo pololu
#define ENCODER_B3 18   // cable blanco pololu  //cable azul va a 5-12V, cable verde y negro a tierra, cable rojo 12V 

//------------------ DEFINICIÓN PINES ULTRASONIDO ----------------
#define ECHO 14
#define TRIG 27

//----------------- VARIABLES DE INTERRUPCIÓN ------------------------
//Variable global de posición compartida con la interrupción motor 1
volatile long theta0 = 0;
long newposition0 = 0;
float position0 = 0;

//Variable global de posición compartida con la interrupción motor 2
volatile long theta1 = 0;
long newposition1 = 0;
float position1 = 0;

//Variable global de posición compartida con la interrupción motor 3
volatile long theta2 = 0;
long newposition2 = 0;
float position2 = 0;

//Variable global de posición compartida con la interrupción motor 4
volatile long theta3 = 0;
long newposition3 = 0;
float position3 = 0;

//Variable global de pulsos compartida con la interrupción
volatile long pulsos0 = 0;
volatile long pulsos1 = 0;
volatile long pulsos2 = 0;
volatile long pulsos3 = 0;
long newpulsos0 = 0;
long newpulsos1 = 0;
long newpulsos2 = 0;
long newpulsos3 = 0;

//Variables de sensor ultrasonico
long duracion, distancia;

//Variables de debouncing
volatile unsigned long tiempoDeInterrupcionAnteriorA0 = 0;
volatile unsigned long tiempoDeInterrupcionAnteriorB0 = 0;
volatile unsigned long tiempoDeInterrupcionAnteriorA1 = 0;
volatile unsigned long tiempoDeInterrupcionAnteriorB1 = 0;
volatile unsigned long tiempoDeInterrupcionAnteriorA2 = 0;
volatile unsigned long tiempoDeInterrupcionAnteriorB2 = 0;
volatile unsigned long tiempoDeInterrupcionAnteriorA3 = 0;
volatile unsigned long tiempoDeInterrupcionAnteriorB3 = 0;
#define tiempoDeRebote 700 

//--------------------------------------------------------------------

//----------------------- VARIABLES GLOBALES GENERALES -------------------
//Tiempo transcurrido y resolcuion de los motores
unsigned long timeold;
float resolution = 1920.0;


//Variable Global Posicion y radio
float radio = 0.064;
float pi = 3.14159265359;

//------- RECEPCION DE DATOS DEDE ARDUINO---------
float pwm_rec = 0;
String leeCadena;         // Almacena la cadena de datos recibida
//----------------------------------------------------------------------

void setup()
{
  Serial.begin (115200);
  Serial.println("start");               
  timeold = 0;

  attachInterrupt(ENCODER_A0, leerEncoder_A0, CHANGE);
  attachInterrupt(ENCODER_B0, leerEncoder_B0, CHANGE);
  attachInterrupt(ENCODER_A1, leerEncoder_A1, CHANGE);
  attachInterrupt(ENCODER_B1, leerEncoder_B1, CHANGE);
  attachInterrupt(ENCODER_A2, leerEncoder_A2, CHANGE);
  attachInterrupt(ENCODER_B2, leerEncoder_B2, CHANGE);
  attachInterrupt(ENCODER_A3, leerEncoder_A3, CHANGE);
  attachInterrupt(ENCODER_B3, leerEncoder_B3, CHANGE);

  // CONFIGURACIÓN PINES SENSOR ULTRASONICO
  pinMode(ECHO, INPUT);
  pinMode(TRIG, OUTPUT);
  
}
void loop()
{
  float rpm0;
  float rpm1;
  float rpm2;
  float rpm3;

  float pos0;
  float pos1;
  float pos2;
  float pos3;

  newpulsos0 = pulsos0;
  newpulsos1 = pulsos1;
  newpulsos2 = pulsos2;
  newpulsos3 = pulsos3;

  // Serial.println("-----------------------");
  digitalWrite(TRIG, LOW);
  delayMicroseconds(2);
  digitalWrite(TRIG, HIGH);
  delayMicroseconds(10);
  digitalWrite(TRIG, LOW);

  duracion = pulseIn(ECHO, HIGH);
  distancia = (duracion / 2) / 29;
  
  if (millis() - timeold >= 100)
  {
    timeold = millis();
    pos0 = (float(theta0 / resolution)) * radio * 2 * pi;
    rpm0 = float(10 * (60.0/ resolution ) * newpulsos0);
    pulsos0 = 0;
    pos1 = (float(theta1 / resolution)) * radio * 2 * pi;
    rpm1 = float(10 * (60.0/ resolution ) * newpulsos1);
    pulsos1 = 0;
    pos2 = (float(theta2 / resolution)) * radio * 2 * pi;
    rpm2 = float(10 * (60.0/ resolution ) * newpulsos2);
    pulsos2 = 0;
    pos3 = (float(theta3 / resolution)) * radio * 2 * pi;
    rpm3 = float(10 * (60.0/ resolution ) * newpulsos3);
    pulsos3 = 0;

    Serial.print("M1: ");
    Serial.print(pos0);
    Serial.print(", M2: ");
    Serial.print(pos1);
    Serial.print(", M3: ");
    Serial.print(pos2);
    Serial.print(", M4: ");
    Serial.print(pos3);
    Serial.print(", DIST: ");
    Serial.println(distancia);

  }

  leeCadena = "";

  
}

// -------------------------------------
// ----- FUNCIONES DE INTERRUPCION -----
// -------------------------------------
void leerEncoder_A0(){
  if(micros() - tiempoDeInterrupcionAnteriorA0 > tiempoDeRebote)
  {
    //Lectura de Velocidad
    pulsos0++; //Incrementa una revolución
    
  //Lectura de Posición  
    int a = digitalRead(ENCODER_A0);
    int b = digitalRead(ENCODER_B0);

    if (a == b){
      theta0--;
    }
    else{
      theta0++;
    }
    tiempoDeInterrupcionAnteriorA0 = micros();
  }
}

void leerEncoder_B0(){
  if(micros() - tiempoDeInterrupcionAnteriorB0 > tiempoDeRebote)
  {
    //Lectura de Velocidad
    pulsos0++; //Incrementa una revolución
      
    //Lectura de Posición  
    int a = digitalRead(ENCODER_A0);
    int b = digitalRead(ENCODER_B0);

    if (a == b){
      theta0++;
    }
    else{
      theta0--;
    }
    tiempoDeInterrupcionAnteriorB0 = micros();
  }
}

void leerEncoder_A1(){
  if(micros() - tiempoDeInterrupcionAnteriorA1 > tiempoDeRebote)
  {
    //Lectura de Velocidad
    pulsos1++; //Incrementa una revolución
    
    //Lectura de Posición  
    int a = digitalRead(ENCODER_A1);
    int b = digitalRead(ENCODER_B1);

    if (a == b){
      theta1++;
    }
    else{
      theta1--;
    }
  tiempoDeInterrupcionAnteriorA1 = micros();
  }
}

void leerEncoder_B1(){
  if(micros() - tiempoDeInterrupcionAnteriorB1 > tiempoDeRebote)
  {
    //Lectura de Velocidad
    pulsos1++; //Incrementa una revolución
    
    //Lectura de Posición  
    int a = digitalRead(ENCODER_A1);
    int b = digitalRead(ENCODER_B1);

    if (a == b){
      theta1--;
    }
    else{
      theta1++;
    }

    tiempoDeInterrupcionAnteriorB1 = micros();
  }
}

void leerEncoder_A2(){
  if(micros() - tiempoDeInterrupcionAnteriorA2 > tiempoDeRebote)
  {
    //Lectura de Velocidad
    pulsos2++; //Incrementa una revolución
    
    //Lectura de Posición  
    int a = digitalRead(ENCODER_A2);
    int b = digitalRead(ENCODER_B2);

    if (a == b){
      theta2++;
    }
    else{
      theta2--;
    }
    tiempoDeInterrupcionAnteriorA2 = micros();
  }
}
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

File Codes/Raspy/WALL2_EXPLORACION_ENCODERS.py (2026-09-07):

import serial
import time

from utils import SmallestSignedAngleBetween

############################################
##### CODIGO PARA QUE EL ROBOT EXPLORE #####
############################################


debounce = 0
debounce_giro = 0

#PARÁMETROS DE COMUNICACIÓN
# ser_ard = serial.Serial("/dev/ttyACM0", baudrate=115200) #Modificar el puerto serie de ser necesario
# ser_esp = serial.Serial("/dev/ttyUSB0", baudrate=115200) #Modificar el puerto serie de ser necesario

ser_ard = serial.Serial("COM6", baudrate=115200) #Modificar el puerto serie de ser necesario
ser_esp = serial.Serial("COM8", baudrate=115200) #Modificar el puerto serie de ser necesario


# ser_esp.reset_input_buffer()
ser_ard.reset_input_buffer()


ang_ref = [0, 90, 180, -90]
ciclo = 0

# VARIABLES DE SENSORES
dist = 100000
pos_1 = 0
pos_2 = 0
pos_3 = 0
pos_4 = 0
pos_wall2 = 0
dist_recor = 0
pwm_base = 50
pwm = 0

##### MODO DE OPERACIÓN DE WALL2 #####
modo = "ESPERA"
accion_exploracion = "AVANZAR"

# PARÁMETROS DE CONTROL DE ANGULO
ref = ang_ref[0]
yaw = 0

kp = 4.8
kd = 0.001
ki = 1.2

kp_1 = 1.2
kd_1 = 0.01
ki_1 = 0.5

err = 0
err1 = 0
err2 = 0

# TIEMPO DE DISCRETIZACIÓN
Tm = 0.01

# TIEMPO DE ESPERA INICIAL
Tw = 0.0
Tw_limit = 2.0

try:
    print("----------- INICIANDO WALL2 MARK5 ------------")
    comando = "RESET"
    comando = comando + "\n"
    comandoBytes = comando.encode()
    # ser_esp.write(comandoBytes)
    ser_ard.write(comandoBytes)

    time.sleep(0.5)

    print("----------- INICIANDO MICROCONTROLADORES ------------")
    while(ser_ard.in_waiting <= 0): pass
    time.sleep(1)
    print("----------- COMENZANDO LECTURAS ------------")
    time.sleep(0.5)

    while True:

        init_loop = time.time()

        if(ser_ard.in_waiting > 0):
            line = ser_ard.readline().decode('utf-8').rstrip().split(":")
            if("YAW" in line[0]):
                yaw = float(line[1])
        if(ser_esp.in_waiting > 0):
            line = ser_esp.readline().decode('utf-8').rstrip().split(",")
            for words in line:
                words = words.split(":")
                if("M1" in words[0]):
                    pos_1 = float(words[1])

                elif("M2" in words[0]):
                    pos_2 = float(words[1])

                elif("M3" in words[0]):
                    pos_3 = float(words[1])

                elif("M4" in words[0]):
                    pos_4 = float(words[1])

                elif("DIST" in words[0]):
                    dist = float(words[1])

        pos_wall2 = (pos_1 + pos_2 + pos_3 + pos_4) / 4

        if(modo == "ESPERA"):
            Tw += time.time() - init_loop
            print("ESTOY ESPERANDO, ME QUEDAN %f SEGUNDOS EN ESTE MODO"  %(Tw_limit - Tw))
            if (Tw >= Tw_limit):
                modo = "EXPLORACION"

        if(modo == "EXPLORACION"):

            if(dist < 50):
                modo = "OBSTACULO"

            if(pos_wall2 - dist_recor >= 4.0 - 0.3 * (ciclo//3)):
                accion_exploracion = "GIRAR"
                ciclo += 1
                ref = ang_ref[(ciclo) % 4]
                dist_recor = pos_wall2


            err = SmallestSignedAngleBetween(yaw, ref)

            if(accion_exploracion == "AVANZAR"):
                pwm_base = 70
            elif(accion_exploracion == "GIRAR"):
                debounce_giro += 1
                pwm_base = 0
                if(err < 10 and debounce_giro > 100):
                    accion_exploracion == "AVANZAR"
                    dist_recor = pos_wall2
                    debounce_giro = 0

            if(pwm_base != 0):
                pwm = pwm + (kp + kd/Tm)*err + (-kp + ki * Tm - 2*kd/Tm)*err1 + (kd/Tm)*err2

            elif(pwm_base == 0):
                pwm = pwm + (kp_1 + kd_1/Tm)*err + (-kp_1 + ki_1 * Tm - 2*kd_1/Tm)*err1 + (kd_1/Tm)*err2

            err2 = err1
            err1 = err

            pwmL = pwm_base - int(pwm)
            pwmR = pwm_base + int(pwm)

            pwmL = int(pwmL) if( -255 <= pwmL <= 255) else int(255 * (abs(pwmL) / pwmL))
            pwmR = int(pwmR) if( -255 <= pwmR <= 255) else int(255 * (abs(pwmR) / pwmR))

            comando = "SETLEFT" + str(pwmL)
            comando = comando + "\n"
            comandoBytes = comando.encode()
            ser_ard.write(comandoBytes)

            time.sleep(0.0001)

            comando = "SETRIGHT" + str(pwmL)
            comando = comando + "\n"
            comandoBytes = comando.encode()
            ser_ard.write(comandoBytes)

            print("POS WALL2: ", pos_wall2, "DIST: ", dist, "REF: ", ref,  "YAW: ", yaw, "pwmL: ", pwmL, "pwmR: ", pwmR)



        if(modo == "OBSTACULO"):

            print("NOS HEMOS ENCONTRADO CON UN OBSTACULO, DETENER ROBOT AHORA!")
            comando = "SETLEFT" + str(0)
            comando = comando + "\n"
            comandoBytes = comando.encode()
            ser_ard.write(comandoBytes)

            if(dist > 50):
                modo = "EXPLORACION"

       



except KeyboardInterrupt:
    print("\nInterrupcion por teclado")
except ValueError as ve:
    print(ve)
    print("Otra interrupcion")
finally:
    ser_ard.close()
    # ser_esp.close()
